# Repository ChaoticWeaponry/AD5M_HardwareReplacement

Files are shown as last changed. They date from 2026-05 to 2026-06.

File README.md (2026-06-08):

# AD5M Complete Hardware Replacement
A project for the Flashforge Adventurer 5M concerning complete electronic hardware replacement.  

**Special thanks to FaqT0tum for inspiring the ideas for these mods.**  

> [!WARNING]  
> **There are no warranties after you embark on this project. You must be adept in soldering and wiring.**
> 
> **PLEASE READ ALL READMES AND UNDERSTAND WHAT YOU'RE DOING BEFORE YOU START PURCHASING ITEMS OR MODIFYING YOUR PRINTER**  

A Dremel (or similar) will be required to modify various plastic bits in the rear housing of the printer to accomodate the extra components.

**Main Hardware changes in this guide:**  

-Stock Mainboard replaced with a Manta M8P V2.0 [From Amazon](https://a.co/d/01iEh6Rq)  
    -Mainboard Controller is a Raspberry Pi CM4 [From Amazon](https://a.co/d/0gnUiEp3)  
-Stock Toolhead board replaced with a MellowFly SB2040 Pro Max V3 [From AliExpress](https://www.aliexpress.us/item/3256806597664801.html)  
-Stock PSU replaced with a Meanwell LRS 450 [From Amazon](https://a.co/d/0aqzs9kM)  
-Stock Display replaced with a BTT Touch HDMI5 v1.2 [From Amazon](https://a.co/d/09CFqlyS)  
-Stock Hotend replaced with a X1/X1C hotend (I used Microswiss) [From Amazon](https://a.co/d/0eQoXAdD)  

**Generic parts needed:**  

-Various M3 screws/nuts (machine thread)  
-M3 thread inserts  
-Various M3 screws (coarse/plastic thread)  
-Various M2 screws (coarse/plastic thread)  
-Various JST XH, PH and MX connectors/pins (MX for the part-fan)  
-12, 16, 18, 22 and 24 gauge wiring (longest lengths will be 18 and 24 gauge for the toolhead harness)  
-A LOT of a robust filament that can handle stress and heat (I used PETG-CF)  

> [!NOTE]
> **Section or part specific parts will be listed in their respective sections.**  

**Please feel free to reach out if something doesn't make sense or specific details are missing, I tried to be thorough with the write-up, but it has taken a long time.**

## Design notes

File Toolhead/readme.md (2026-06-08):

# Toolhead Section  

**Document of Schematics/Installation/Configuration** [Fly Wiki](https://mellow.klipper.cn/en/docs/category/fly-sb2040-pro-v3)  

Specific Parts Needed  

-2X Honeywell SM453R Omnipolar Magnetic Switch (T092-3) [From DigiKey](https://www.digikey.com/short/qbd3v8pj) (I would buy extra just in case)  
-A right angle 2 pin JST-XH connector for the hotend connection.  
-A set of '2x2' Molex Microfit 3.0 connectors (buy a couple so you have extras) [From Amazon](https://a.co/d/008s7Y0V)  
-A set of 9x9x12 Stick on Heatsinks for the Motor Driver [From Amazon](https://a.co/d/09exRvM4)  
-A 30x15mm 24v fan, 2 wire.  
-A straight 2 pin JST-XH connector for the hotend thermistor (you need to change the X1 thermistor connector to JST-XH)  
-Some 1/4" PET braided sleeving to protect the wiring harness [From Amazon](https://a.co/d/0aQ7BoMF)  

> [!NOTE]
> Make sure you purchase the correct Molex Microfit 3.0 pins, a lot of listings support 20-24 gauge wiring, you must purchase 18 gauge specific pins for the power connections.

The XT30 power connector, side pin header for the secondary board, thermistor connector, hotend connector, fan header and extruder motor connectors will need to be removed/desoldered. If you have a desoldering pump, it will make your life easier when you install the replacement connectors and wiring.  

**Before:**  
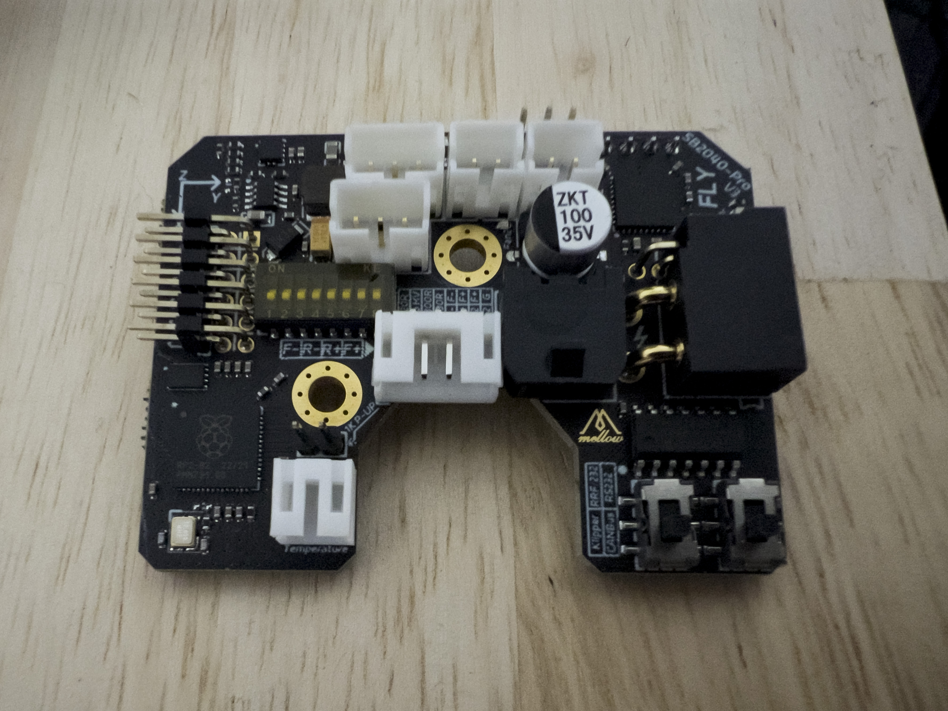
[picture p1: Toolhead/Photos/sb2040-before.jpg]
Before Removal
  
**After:**  
After Removal  

> [!NOTE]
> In my case, using a small set of flush cutters to cut the XT30 pins individually helped with desoldering. The rest of the pins didn't give me many issues.  

**SB2040 Pinout:**  
SB2040 Pinout  

**SB2040 Wiring:**  
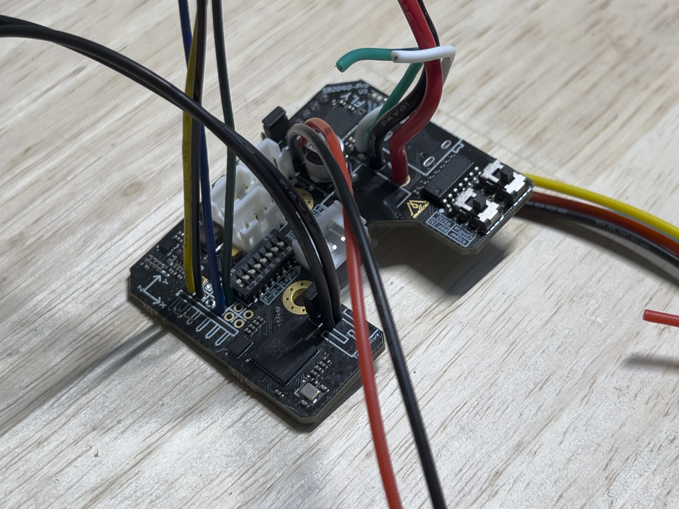
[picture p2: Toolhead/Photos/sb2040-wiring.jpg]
SB2040 Wiring
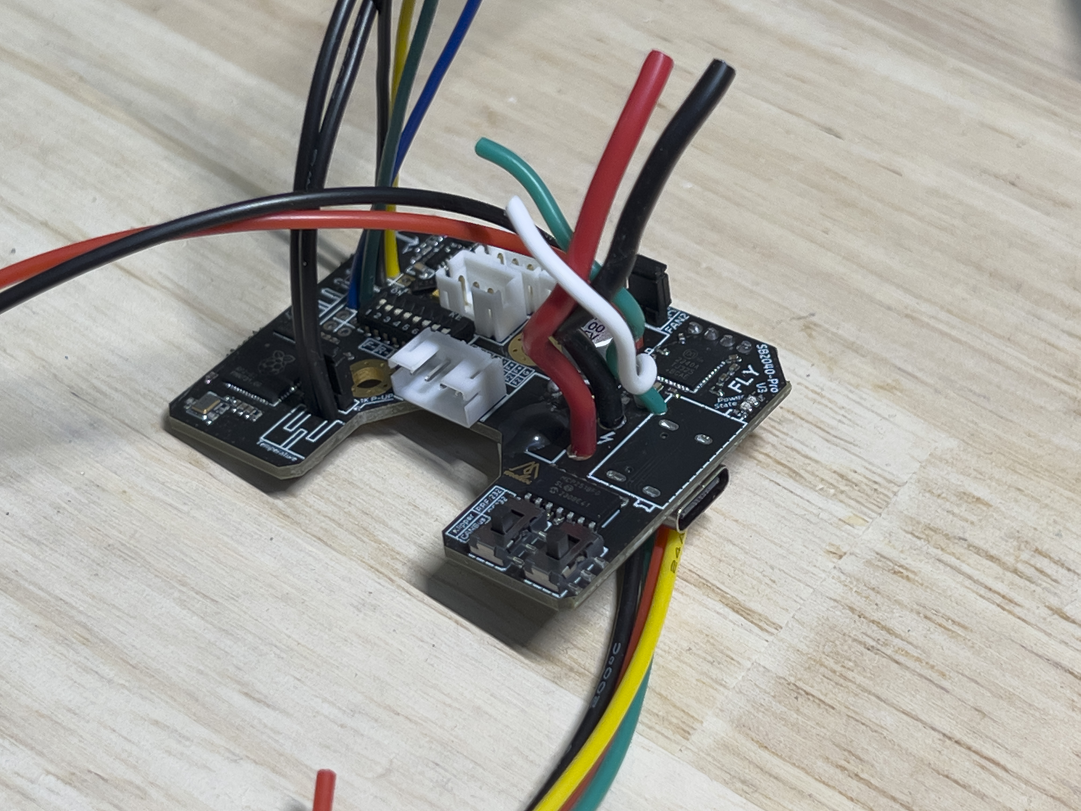
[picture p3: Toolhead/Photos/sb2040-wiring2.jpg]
SB2040 Wiring
   
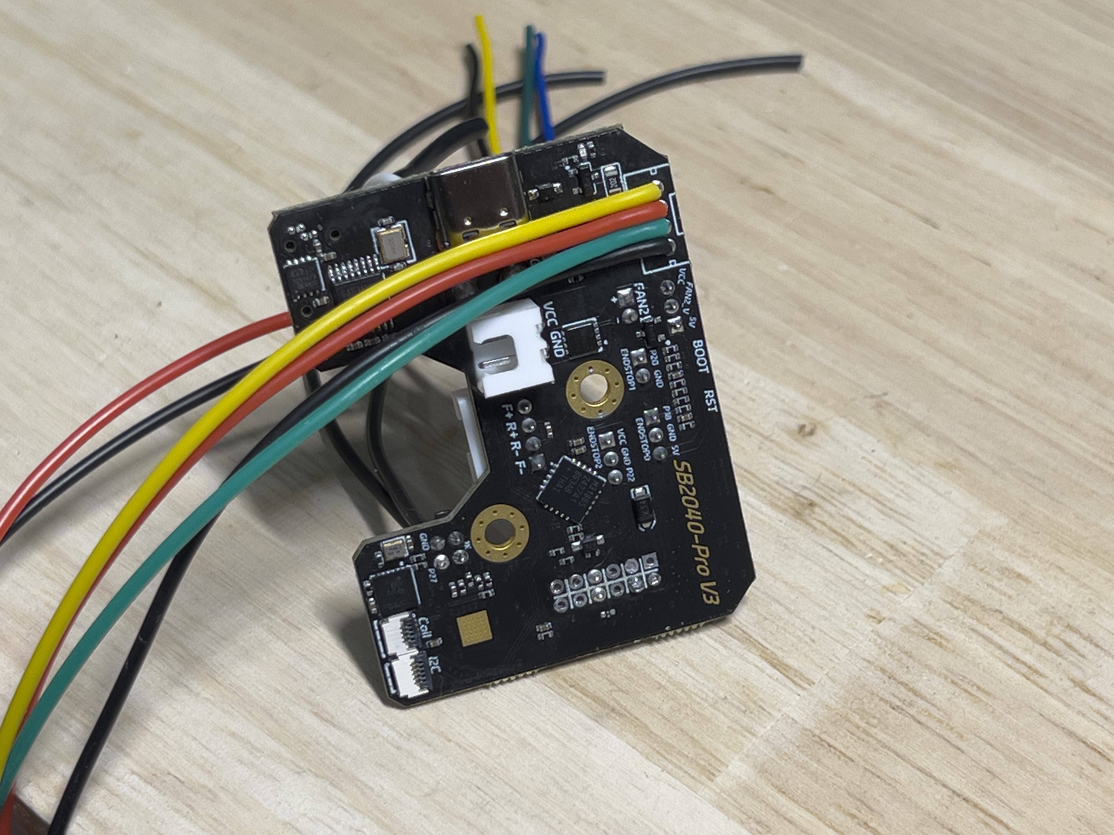
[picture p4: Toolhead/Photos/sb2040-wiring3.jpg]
SB2040 Wiring
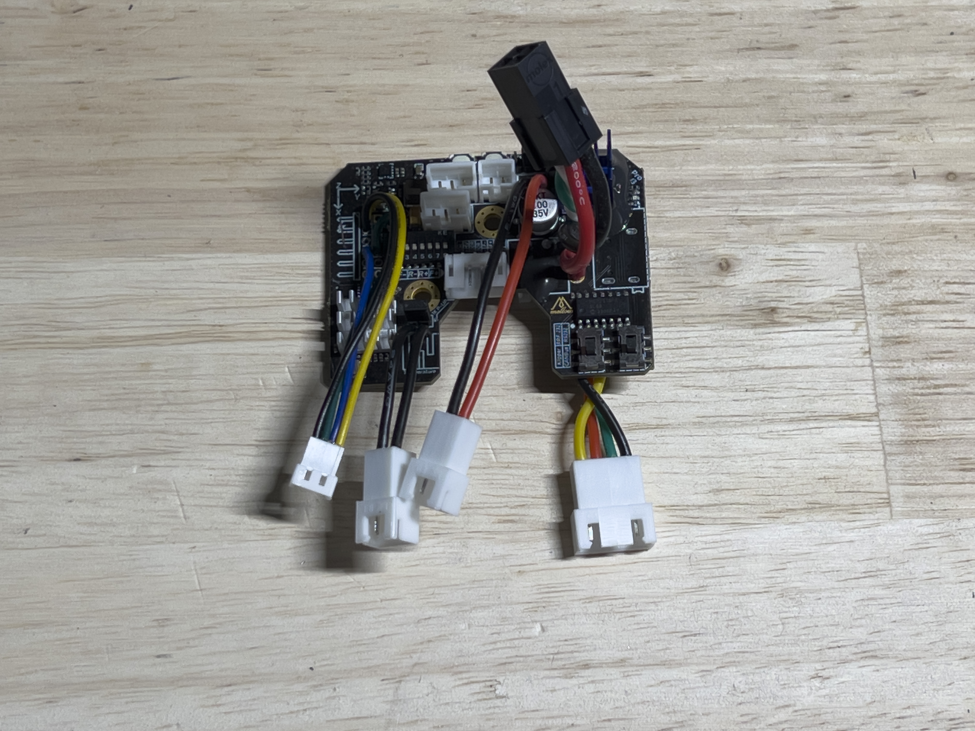
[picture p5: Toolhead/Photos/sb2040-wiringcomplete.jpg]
SB2040 Completed Wiring
   

> [!NOTE]
> I used 18 gauge wiring for the main power to the Molex Microfit 3.0 and 24 gauge wiring for the rest of the circuits.  
> I would recommend smaller wiring for the part fan connector (I disassembled some PC fan extension cables), the JST MX connectors/pins are ***TINY.***

**Toolhead Connectors:**  
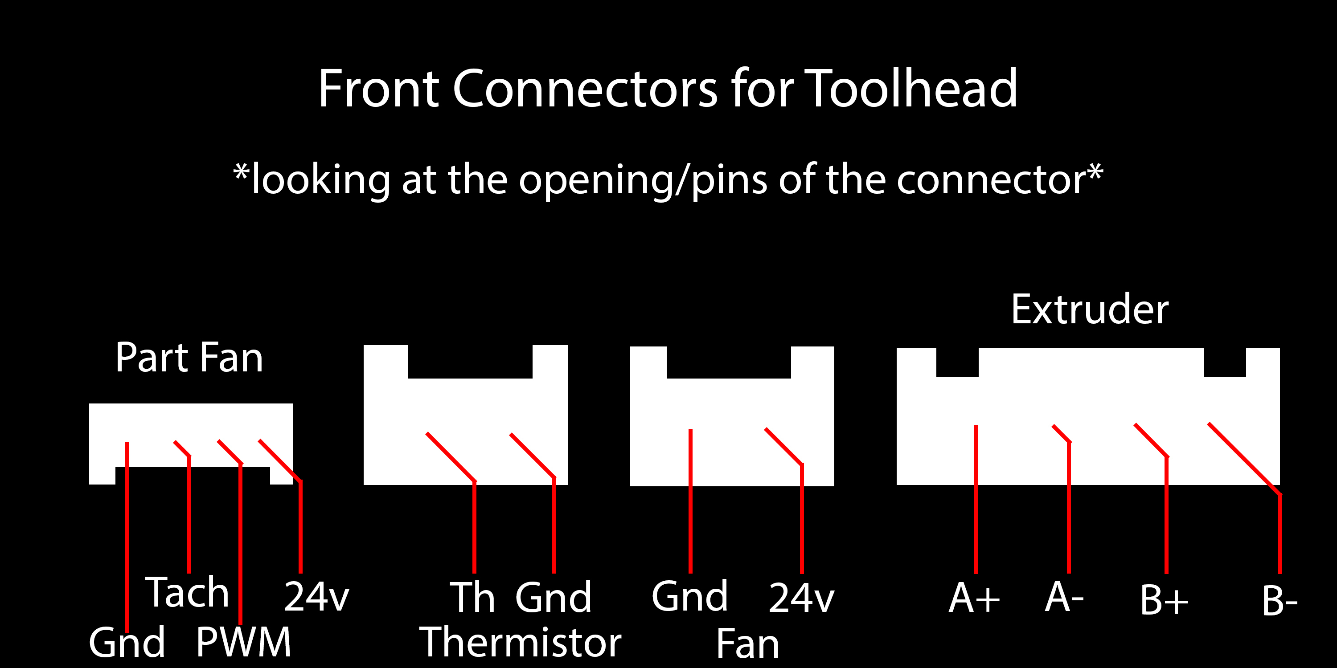
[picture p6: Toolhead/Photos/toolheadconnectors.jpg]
Toolhead Connectors
  

I would strongly recommend upgrading the SB2040's included driver heatsink, I used a 'stick-on' 9x9x12mm heatsink and potted it to assist with vibration resistance. I added a small heatsink to the Raspberry Pi controller as well.  
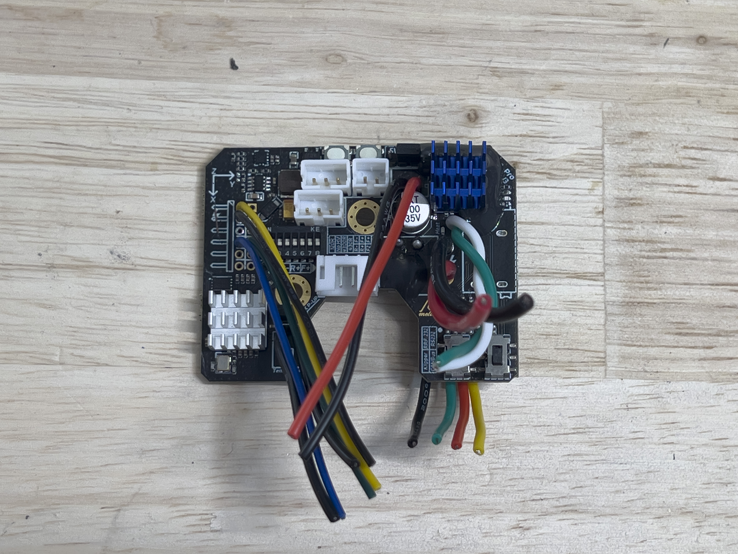
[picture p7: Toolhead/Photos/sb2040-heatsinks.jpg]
SB2040 Heatsinks
  

**Part Fan:**  
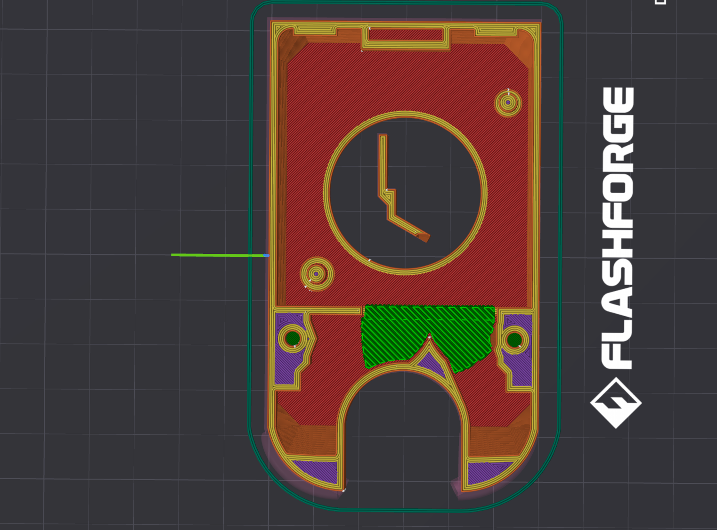
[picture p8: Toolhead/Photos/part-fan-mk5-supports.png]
Part Fan Supports
  
Make sure you use support painting on the part fan, above is a general guideline for where the supports should be.  

**Toolhead Body:**  
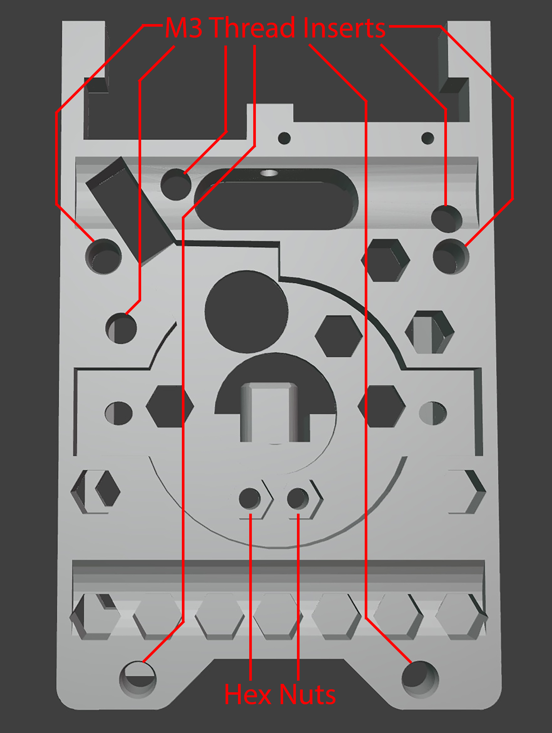
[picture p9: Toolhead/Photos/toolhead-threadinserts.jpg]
Toolhead Thread Inserts
  
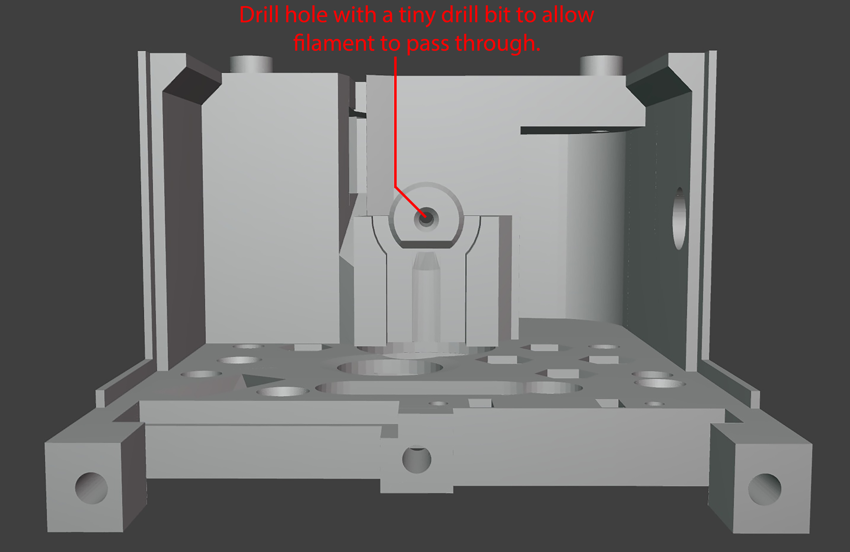
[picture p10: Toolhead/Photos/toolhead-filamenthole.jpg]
Toolhead Filament Hole
  

**Toolhead MR Sensors:**  
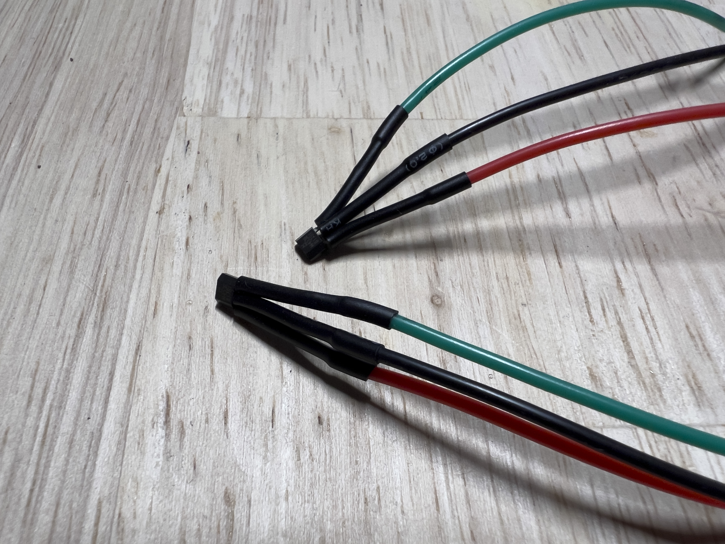
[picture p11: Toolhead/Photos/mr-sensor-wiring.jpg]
MR Sensor Wiring
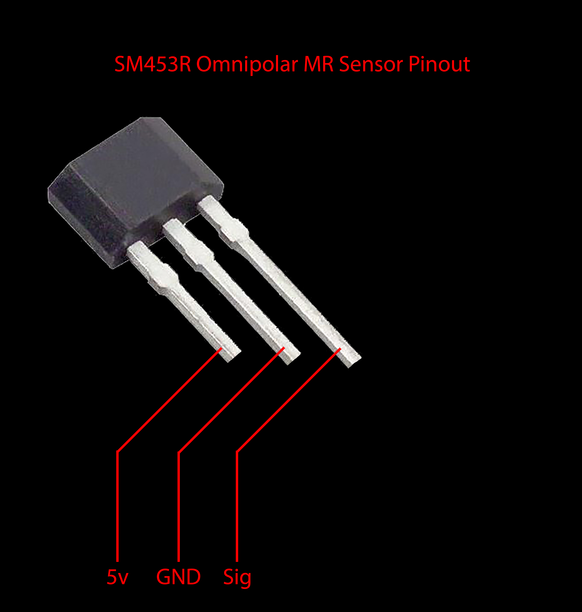
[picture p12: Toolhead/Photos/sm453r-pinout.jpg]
MR Sensor Pinout
   

> [!NOTE]
> When inserting the MR sensors into the toolhead cap, make sure they are completely bottomed out, the top of the sensor (opposite of the leads) is inserted first, the holes should be a snug fit. Only epoxy the areas surrounding the MR sensor to hold it in place. Epoxy ***should not*** contact the sensing faces.
> 
> In my case, it was easiest to trim the leads to ~1/2 the original length, solder the wires, heatshrink the connections, then bend everything to a 90 degree angle. The rounded face of the sensor should face the bottom on the Y endstop, towards the front on the X endstop.  

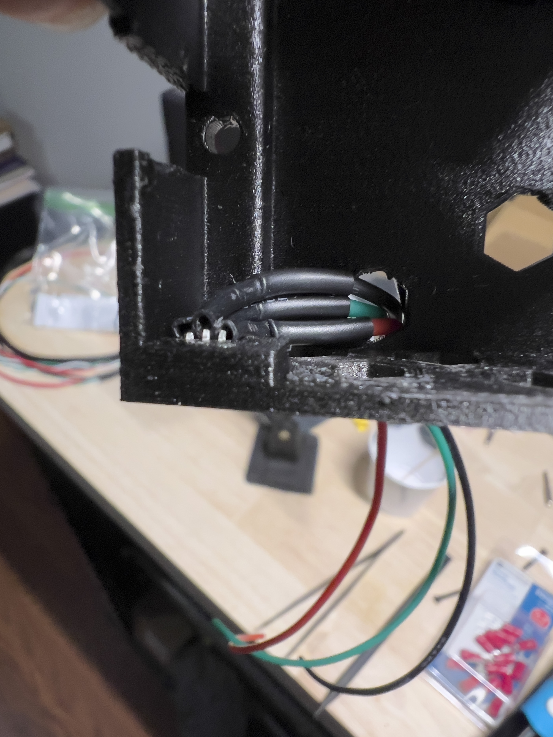
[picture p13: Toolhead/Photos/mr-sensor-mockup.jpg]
MR Sensor Mockup
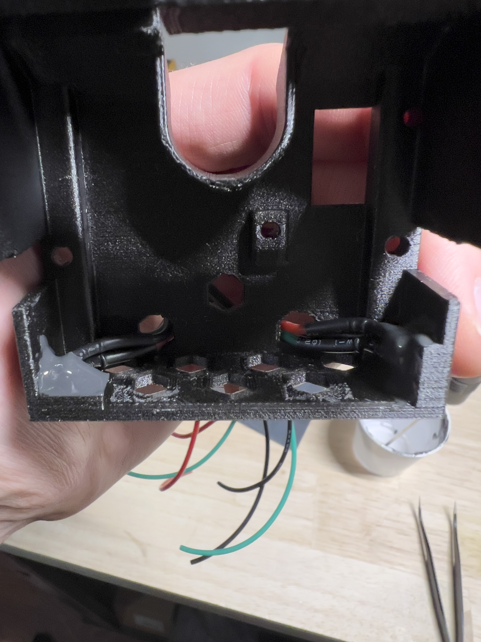
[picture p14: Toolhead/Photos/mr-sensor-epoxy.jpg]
MR Sensor Epoxy
   

The MR sensors will be ***sharing a 5v pin*** from the 3pin endstop connector. The Y endstop sensor will utilize the 3pin endstop connector, the X endstop sensor will utilize the 2pin endstop connector.  
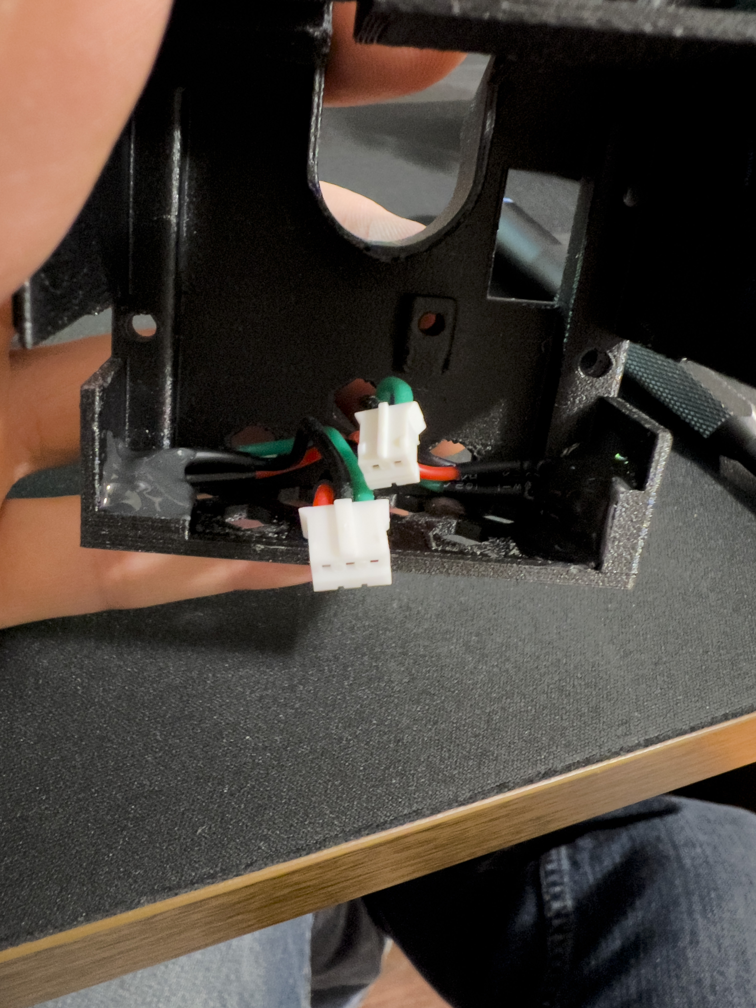
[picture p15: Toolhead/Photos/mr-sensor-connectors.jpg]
MR Sensor Connectors
  

**Original Extruder Modifications:**  
You will need to cut off the original 30x10 fan mounts from the stock extruder and remove the top tabs that hold the original fan wiring. This will make the top flush and give more room around the extruder.  

**Toolhead Cap:**  
The printed part of the toolhead cap has 2 'shields' built into it to prevent supports from building on the MR sensor areas.  

**Toolhead Harness:**  
I intentionally made my harness long so I could shorten later. My harness was a little over 1 meter long when completed.  
It will be 2x 18 gauge power wires and 2x 24 gauge CAN wires. Make sure you twist the 24 gauge wires to avoid interference.  
I used a braided PET sleeve to cover and protect the wires from chafing. Heat shrink over the end of the sleeving near the toolhead connector (where the clamp is).  

**Toolhead Assembly Order:**  

1: Toolhead body prep, insert heat-set inserts and hex nuts for the hotend. Drill out 'tube' between extruder and hotend with a tiny drill bit.  
2: Install hotend. Apply blue threadlocker to the M3 screws. I make sure the hotend is bottomed out while torquing the screws.  
3: Install 30x15 hotend fan, intake from the outside blowing air toward the hotend.  
4: Install extruder motor to the toolhead assembly, route wiring through the rectangular hole.  
5: Install extruder assembly and tighten the 3 screws.  
6: Install printed part "board mount" that is located just above the extruder. You may wish to use M2 coarse screws to clamp in place, they are recommended but not absolutely neccessary.  
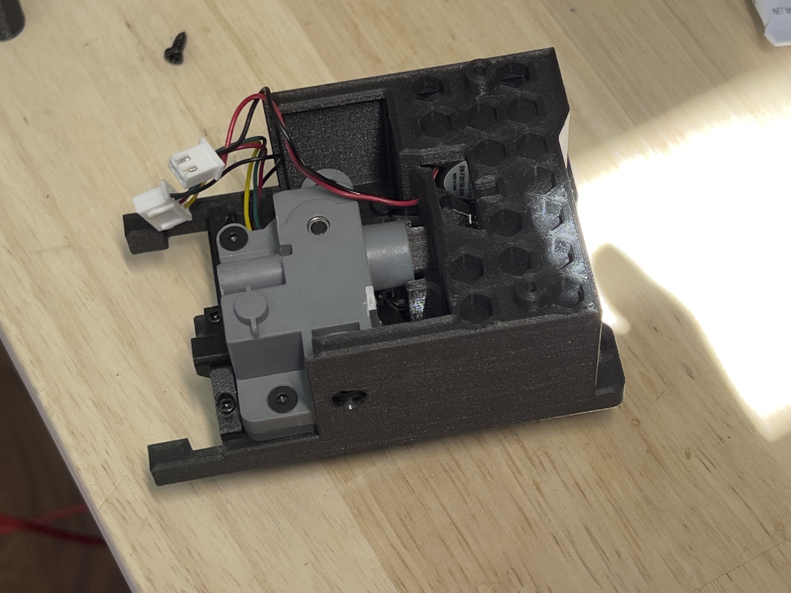
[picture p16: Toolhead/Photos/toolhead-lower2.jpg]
Toolhead Lower
  
7: Install SB2040 board using 2 coarse M3 screws. Plug in hotend heater connection.  
8: Install the toolhead cap, plug in the MR sensors, then fiddle with the connectors to get them routed correctly. The 2x2 4pin Molex Microfit main connection exits the cap on the top rectangular hole. The 4 other connectors should route to the front and 'clip' in place.  
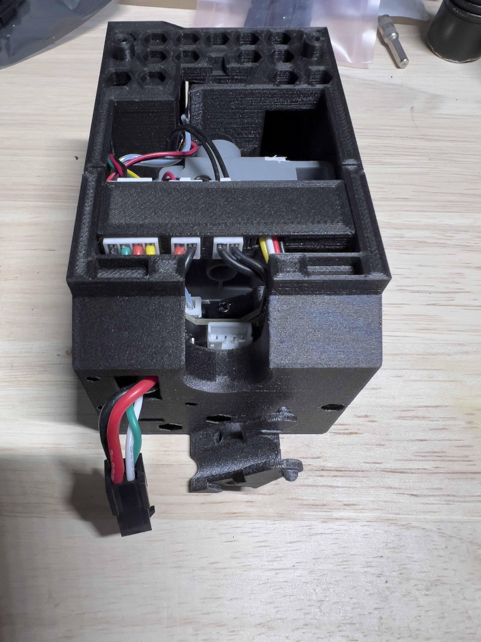
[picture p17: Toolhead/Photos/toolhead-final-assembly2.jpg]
Toolhead Final Assembly
  
9: Install front connector cover over the 4 different JST connections. Install the extruder guide (slide over the top of the extruder, it has a slot to interface correctly).  
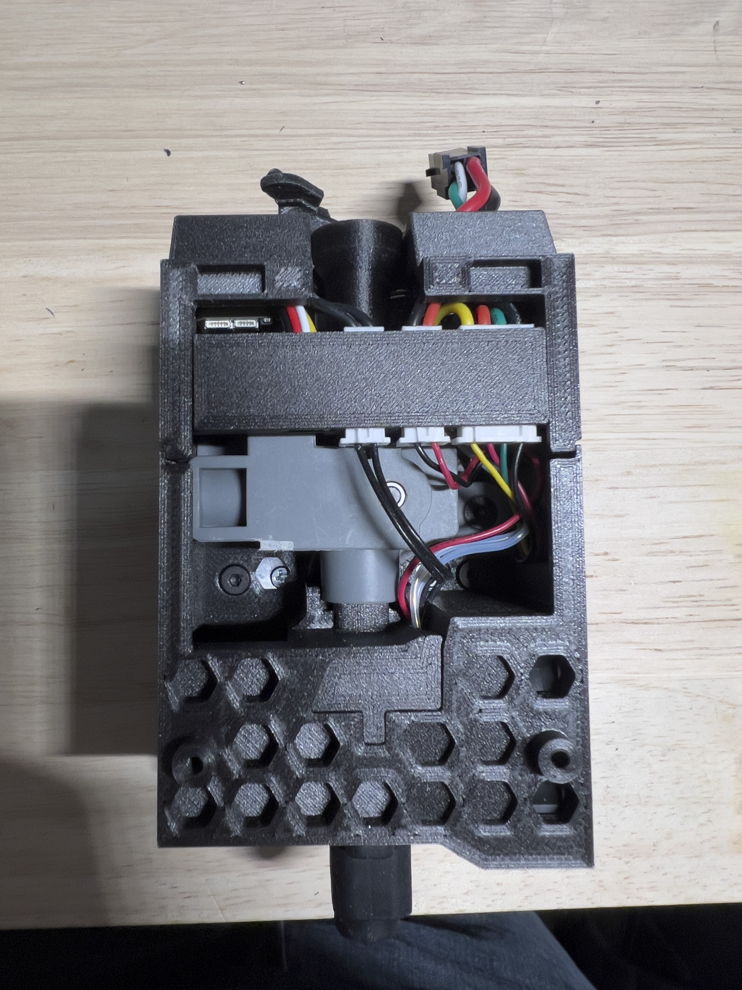
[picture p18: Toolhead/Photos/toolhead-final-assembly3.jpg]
Toolhead Final Assembly
  
10: Plug in extruder motor, hotend fan and hotend thermistor connections.  
11: Install printed part "partfan gap filler" to part fan assembly, it should be a snug fit.  
12: Install part fan to toolhead assembly, route wiring so it doesn't get pinched. Secure with M3x16 coarse screws.  
13: Install/connect main wiring harness to toolhead, attach strain relief connection and tighten screws with the wiring in the correct location.  
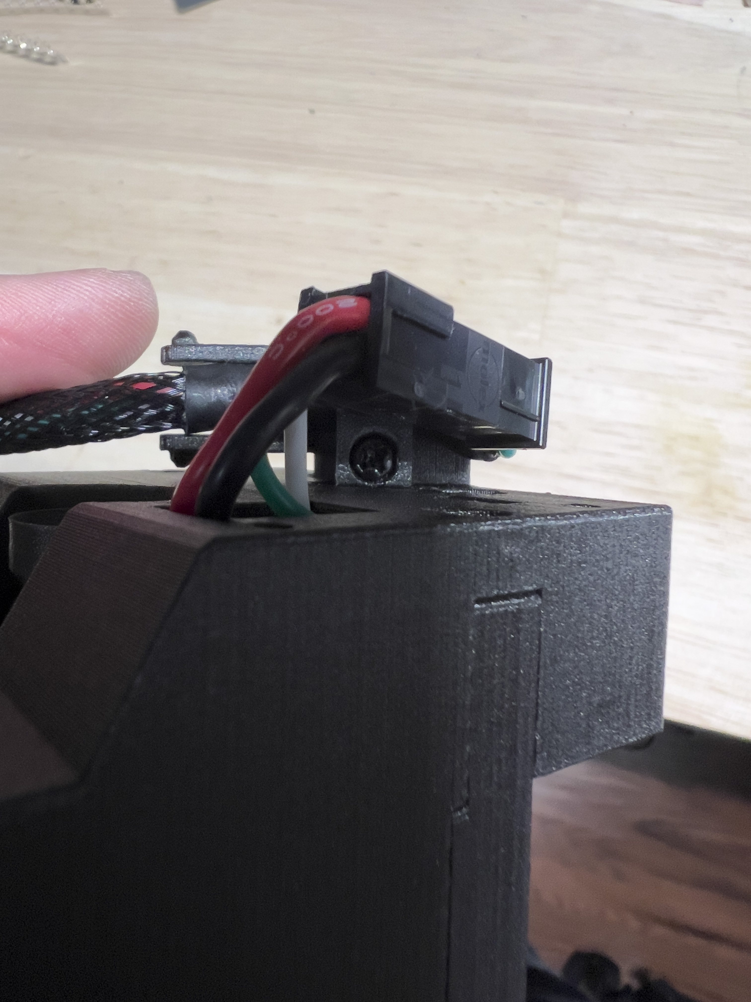
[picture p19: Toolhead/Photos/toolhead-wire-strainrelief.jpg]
Toolhead Wiring Strain Relief
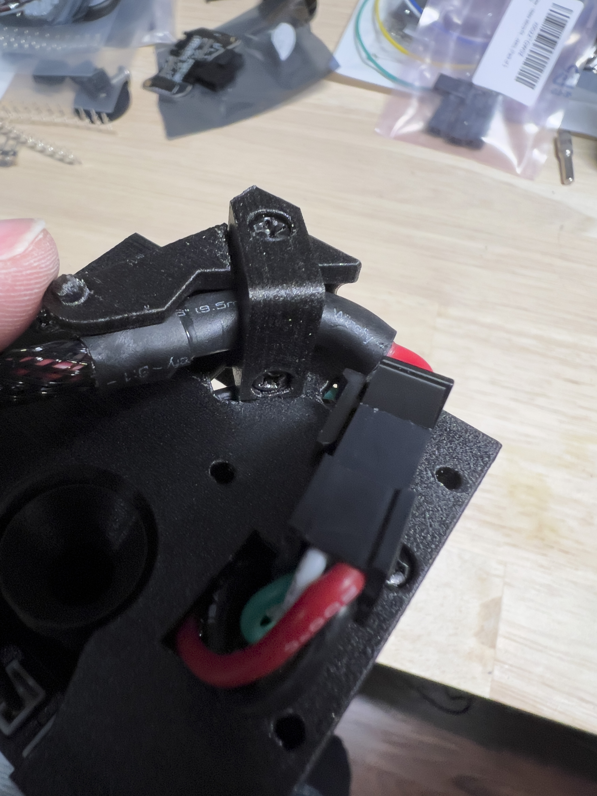
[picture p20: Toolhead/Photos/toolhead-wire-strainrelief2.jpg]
Toolhead Wiring Strain Relief
  
14: Install printed part "molex housing" with 3 M3x8 coarse screws, the Molex Microfit housing should have the release tab facing the center of the toolhead cap, it will only install one way.  
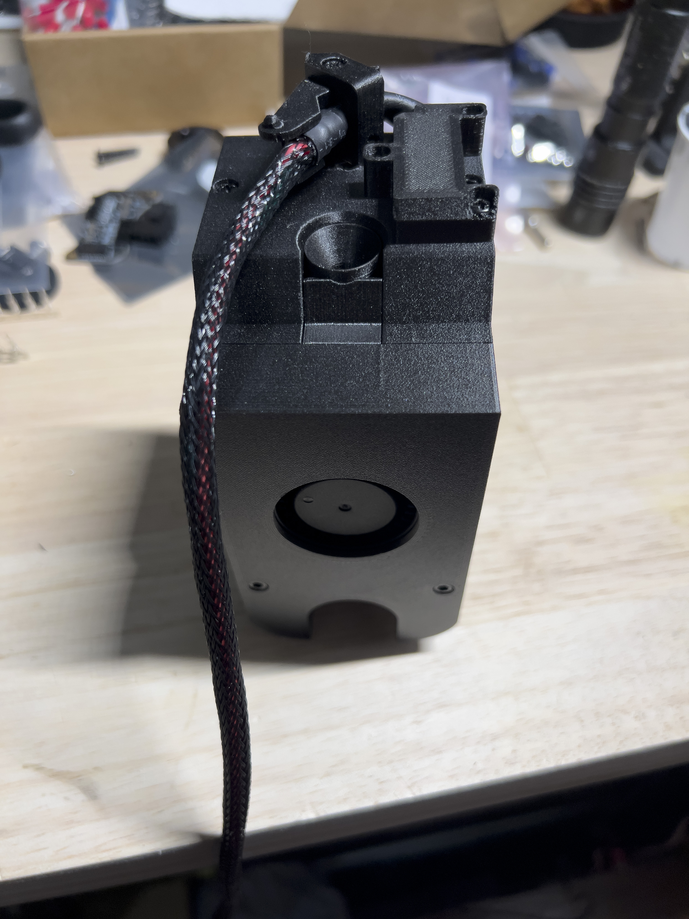
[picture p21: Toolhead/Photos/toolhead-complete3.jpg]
Toolhead Complete
  
The main assembly should be complete, route wiring harness through your drag chain assembly and back to the grommet on the printer.  

>[!NOTE]
>You may need to adjust the endstop position on the X/Y axes. This may vary depending on magnets or sensor sensitivity.  
>
>
>For X axis: Home the printer, move the head to +/- 100 and measure between the edge of the toolhead cap and the frame, compare side to side. Adjust the X endstop position until distance from toolhead to frame is the same side to side.  
>**Example:** edge of toolhead to frame at position 100 is 17mm, edge of toolhead to frame at position -100 is 13mm would mean the endstop position in the configuration would have to change by 2mm to make both measurements 15mm.  
>
>
>For Y axis: Home the printer, slowly move the toolhead until the cap is 1-2mm from contacting the front edge of the frame. Adjust the Y endstop position until you can reach -110 and have a very small gap between the toolhead cap and the front frame.

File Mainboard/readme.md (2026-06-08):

# Mainboard Section  

**Document of Schematics/Installation/Configuration** [BTT Wiki](https://global.bttwiki.com/M8P-V2_0.html)  

Parts Required:  

-FPC 30p 1mm PCB (For adapting the AD5M bed ribbon to interface with the new mainboard) [From Amazon](https://a.co/d/09iN6a9x)  
-Mainboard Dependent - 3 Stepper Motor Drivers (I used TMC2240 with my Manta M8P v2) [From Amazon](https://a.co/d/0ccSFjxs)   
-A large external MOSFET for the bed heater [From Amazon](https://a.co/d/080Fl4P3)  
-A slim 140mm fan [From Amazon](https://a.co/d/0aiYGzja)  

**MOSFET Section:**  
The Manta M8P and many other mainboard come with on-board MOSFETS to drive a bed heater. The M8P is rated to ~10 Amps, which is pretty much exactly the power rating of the stock AD5M bed heater (250w).  

I would *strongly* suggest that you include an external MOSFET like I listed above. It's stupid-overkill regarding power rating, but I would much rather err on the side of caution.  

Follow the pinouts of the respective external MOSFET that you purchase, they should be pretty self-explanatory. 2 terminals for main power in, 2 terminals for bed power out, 2 terminals for bed control (coming from the mainboard).  

**Bed Electrical Connection:**  
Bed Electrical Connections  

Above includes the pinouts for the FPC ribbon cable for the bed, as well as the pinouts for the Z-endstop and filament runout sensors.  

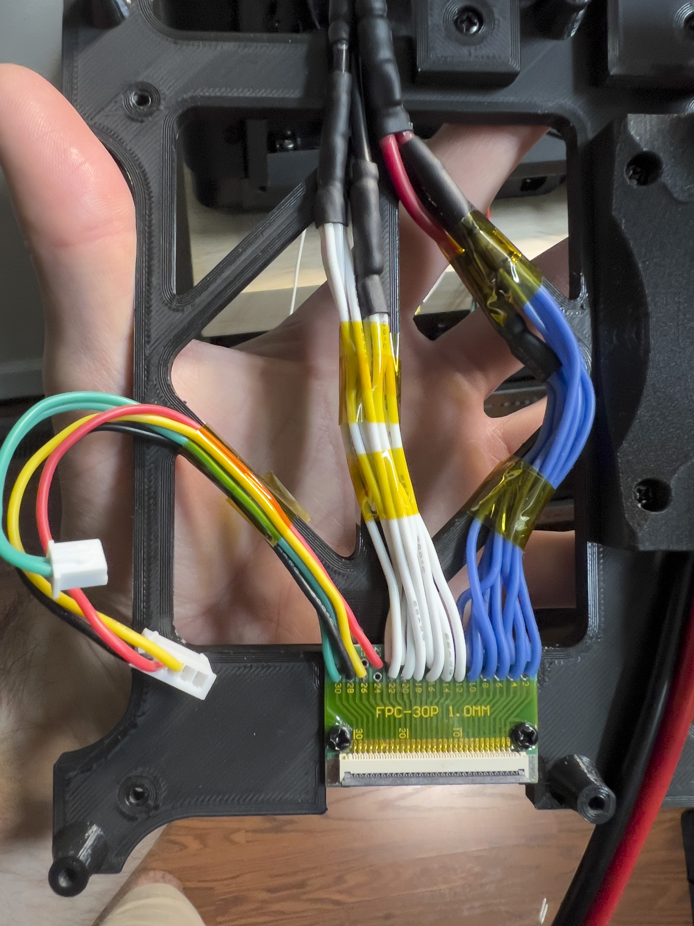
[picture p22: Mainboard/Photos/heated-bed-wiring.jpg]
Heated Bed Wiring
  

Above shows the wiring that I created to adapt to the FPC ribbon. Each one of the heater wires starts as a 22 gauge wire, these are then divided into groups of 5 and 6 and crimped into 2 separate 16 gauge wires. The two 16 gauge wires are crimped into a single 12 gauge wire.  

So for *EACH* pole of the heater, there will be 11x 22 gauge wires spliced into 2x 16 gauge wires spliced into 1x 12 gauge wire.  

**M8P Diagram:**  
M8P Diagram  

>[!NOTE]
>I did not use the filament sensor during my conversion of the printer. You should be able to wire it to any of the endstop connections and configure in your printer configuration.  
>You may elect to add additional thermistors since there are extra slots with the Manta M8P, I used thermistors on all of my stepper motors and added a chamber temperature themistor as well.

The chamber fans that I used (40mm Noctua) and all of the other fans are 12v, so you will need to select the voltages for the fans using their respective jumpers. Follow the manual for the mainboard.  

For the chamber fans, I used 2 pin JST-XH to 4 pin fan adapters, so you will lose PWM control and tachometer. Voltage control will still work to control fan speeds.  

You can re-use the stock X, Y and Z stepper motor wiring, the pinouts do not change.  

**Assembly Order:**  
1: Attech MOSFET bracket to mainboard bracket (2x M3 coarse screws)  
2: Attach FPC ribbon PCB to mainboard bracket (2x M3 coarse screws)  
3: Secure mainboard bracket assembly to the printer back housing (4x M3 coarse screws)  
4: Connect bed ribbon to FPC connector  
5: Secure M8P mainboard to mainboard bracket (4x M3 coarse screws)  
6: Connect all wiring (tweezers will come in handy grabbing the wires on the left edge of the mainboard, space is limited)  
7: Attach 140mm fan bracket to mainboard bracket (2x M3 coarse screws)  
8: Attach the 140mm fan to the fan bracket (2x long M3 coarse screws)  
9: Connect HDMI and USB for the front display  
10: If you are using the included Waveshare WiFi antenna, I have a 3D printed adapter (misc section) that plugs into the ethernet port  

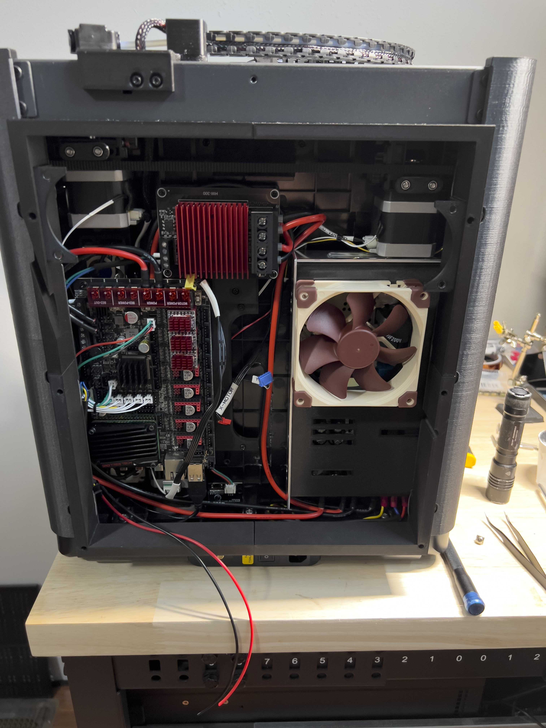
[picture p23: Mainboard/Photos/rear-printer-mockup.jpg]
Rear Printer Mockup
  

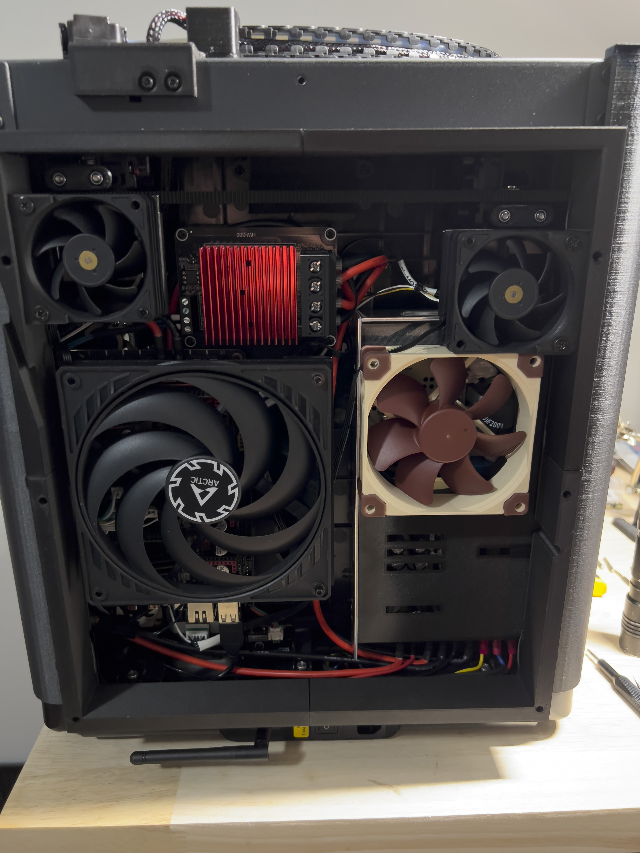
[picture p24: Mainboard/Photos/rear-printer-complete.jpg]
Rear Printer Complete
  

Rear Printer Complete With Top

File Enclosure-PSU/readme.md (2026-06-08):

# Enclosure / PSU Section  

**Parts Needed:**  
-8x 12x3mm magnets for the enclosure top.  
-6x 36mm M4 screws screws for the back housing/cover assembly.  
-3ft/1m HDMI to Micro HDMI & USB-A to USB-C cables for the display.  
-2x 40mm 12v fans for enclosure ventilation.  
-2x 60mm 12v fans for X/Y stepper motor cooling.  

I have included an STL for the replacement front cover for the Meanwell LRS-450 adding support for a 92mm fan. The stock fan runs at 12v.  
**I will not be including instructions or pictures for modification of the PSU for liability reasons. Please be careful.**  

For the overall enclosure for the printer, just use the original Flashforge enclosure kit minus the top. The parts included in the guide are for the top cover and the rear cover (with extensions). The rear covers and extensions will add roughly 40mm of depth to your printer.  

**Front Screen:**  
The back cover of the BTT Touch 5 is mounted to the top of the enclosure ***first***.  
The screen itself is pressure fit into the front cover, then you slide the front cover over the rear cover and secure with 2 M2 coarse-threaded screws.  

**Back Housing Mods:**  
Back Housing Mods for PSU  
Back Housing Mods for Mainboard  

The LRS-450 shares the same mount as the LRS-350 (and the original power supply), so no modifications are needed on the mount holes themselves.  
The entire shroud for the top enclosure fan will need to be cut flush (or close to flush) for the new board to fit.  
A lot of this will be trial and error, test fit, remove more material, test fit again, etc.  

**Top Housing:**  
I have no in-progress shots while making this, but it should be pretty self-explanatory. Print the parts, place on a large, level surface, glue together with your choice of adhesive. I generally glue the magnets into the slots after the top is glued into one piece.  
There are 2 spots for M3 thread inserts for the screen mount, make sure these are slightly recessed so the screen housing can mount flush to the top assembly. The USB and HDMI cables should slot nicely into the groove in the right side of the top assembly.  

Startup Test  

**Rear Extensions and Cover:**  
The rear extension pieces are pressure fit into each other, I placed double sided tape on the inside edge, then used the M4 screws to align the extension pieces. This will allow you to install/remove the rear cover without struggling to line multiple things up.  
The top-left extension piece has a groove cut into it to allow the USB and HDMI cables from the screen to pass through.  

The rear covers are held together with 8 total M3x10 coarse thread screws. They have tabs in the corners to help line the assemblies up.  
Back Cover Installed

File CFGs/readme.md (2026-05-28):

# Configuration Section  

The files contained in this section are a slightly modified version of the configurations of my printer. I have some optional accessories (buzzer, extra temperature sensors, different stepper motors, etc).  

**PLEASE GO THROUGH THE CONFIGURATION FILES TO MAKE SURE THEY WILL BE COMPATIBLE WITH YOUR SPECIFIC HARDWARE CONFIGURATION**  

> [!WARNING]
> Your CAN UUID's will be different than mine, follow the respective instructions for your toolhead board and mainboard to find yours.

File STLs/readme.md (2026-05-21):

# STL Section

Included in this section are all of the STL's required for the conversion.

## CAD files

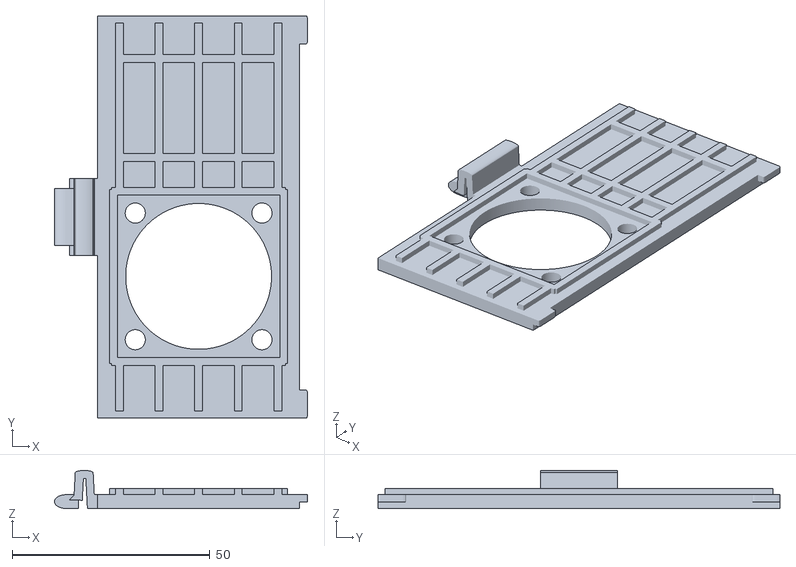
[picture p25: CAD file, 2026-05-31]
STLs/Enclosure-PSU/fanfilter-40mm-upper.stl
63.9 x 101.5 x 9.60

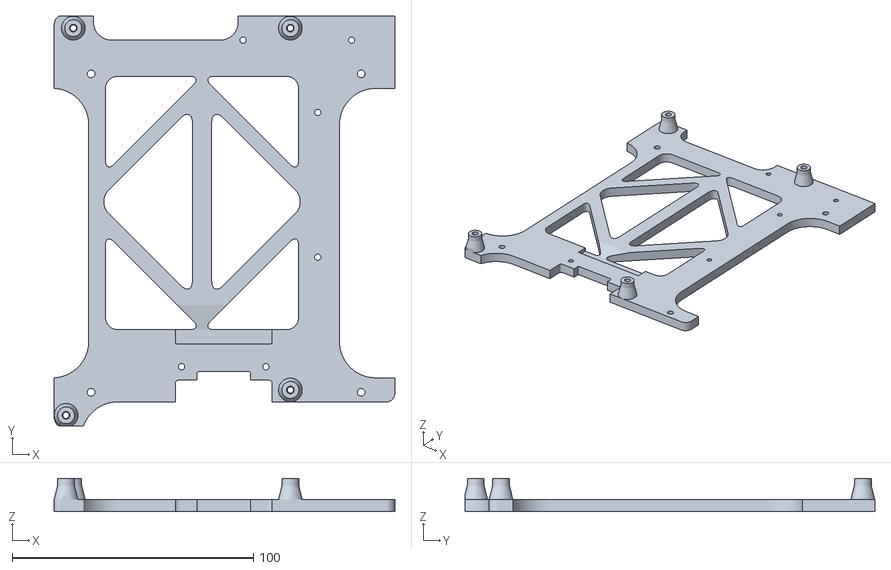
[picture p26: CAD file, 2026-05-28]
STLs/Mainboard/mantam8p-ffad5m-adapter-mk2-base.stl
141.4 x 170.0 x 13.7

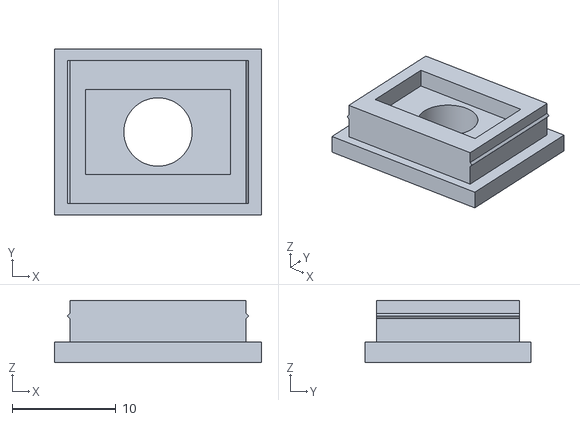
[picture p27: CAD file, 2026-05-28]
STLs/Misc/ad5m-wifi-antenna-adapter-mk1.stl
20.0 x 16.0 x 6.00

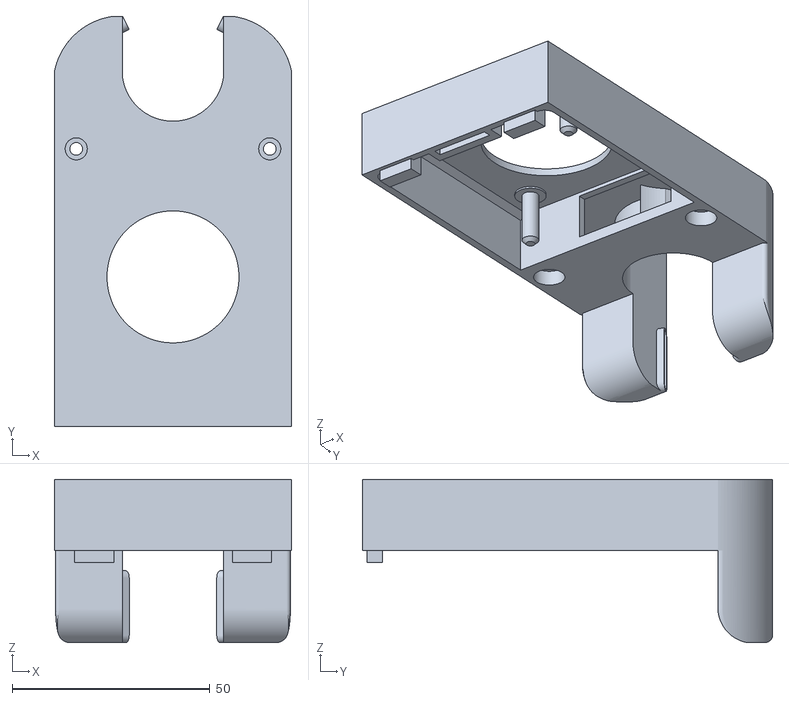
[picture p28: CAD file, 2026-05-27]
STLs/Toolhead/extruder-x1-sb2040-mk5-partfan-clearanced.stl
60.0 x 103.8 x 41.3

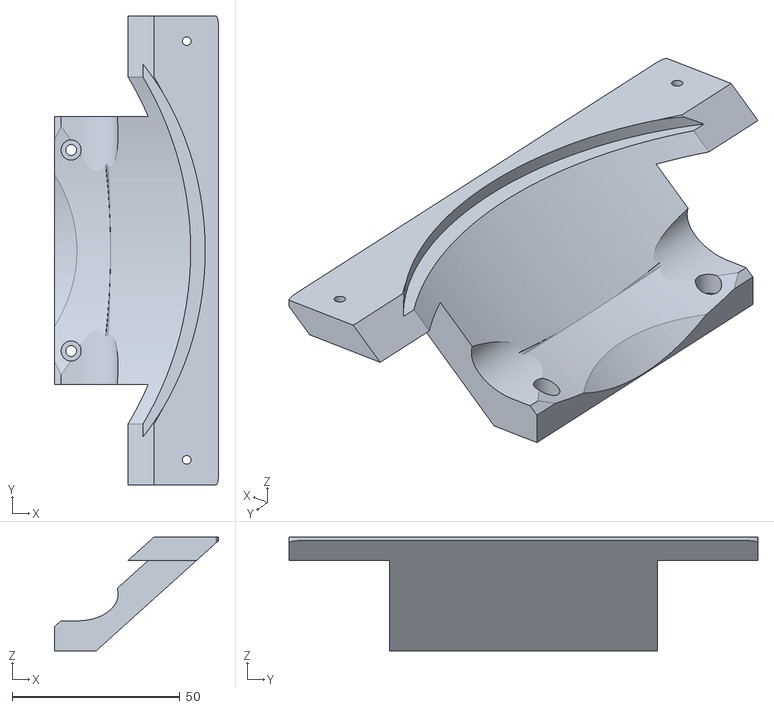
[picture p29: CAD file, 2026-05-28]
STLs/Mainboard/mantam8p-ffad5m-adapter-140fan-mk5.stl
49.0 x 140.0 x 34.0

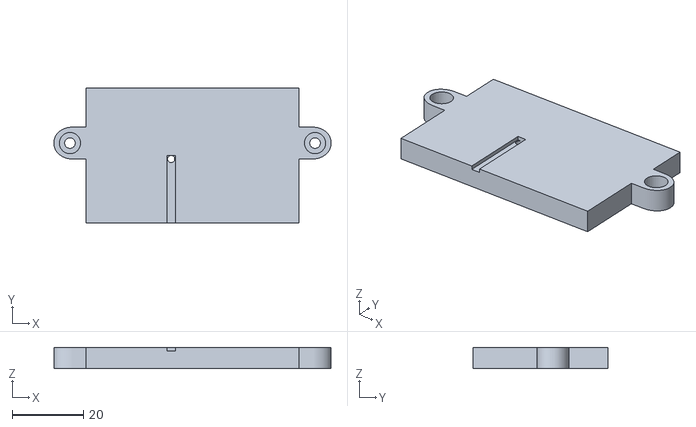
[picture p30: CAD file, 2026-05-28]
STLs/Misc/mantam8p-ffad5m-adapter-mk2-chamber-thermistorplate.stl
78.0 x 38.0 x 6.00

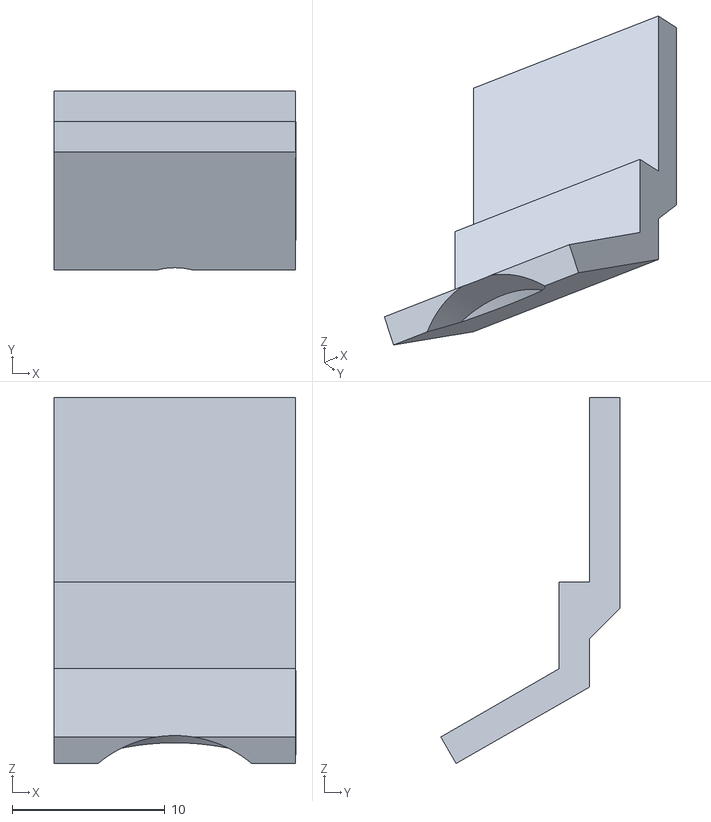
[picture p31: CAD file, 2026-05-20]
STLs/Toolhead/extruder-x1-sb2040-mk5-partfan-gapfiller.stl
15.8 x 11.7 x 23.9

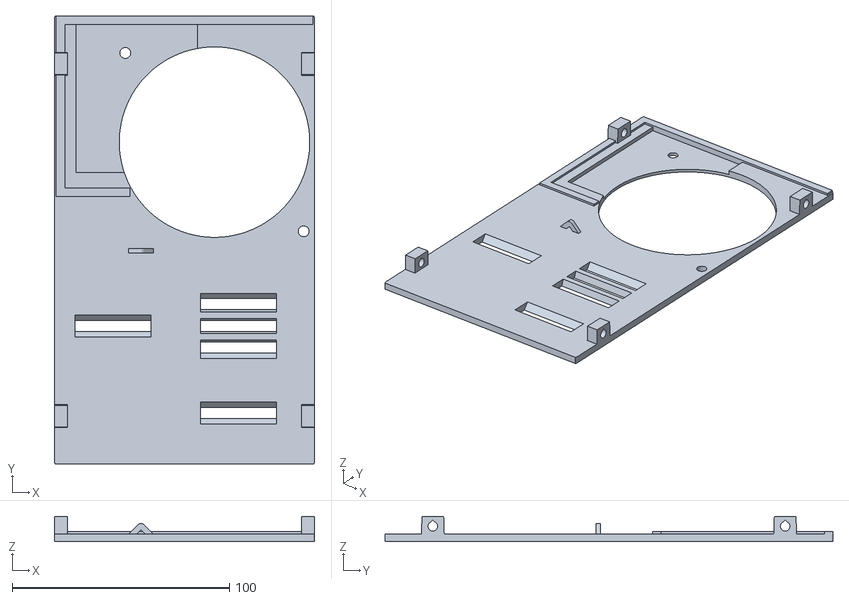
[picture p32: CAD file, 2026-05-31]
STLs/Enclosure-PSU/mw-lrs450-frontpanel-mk2.stl
119.6 x 206.0 x 11.5

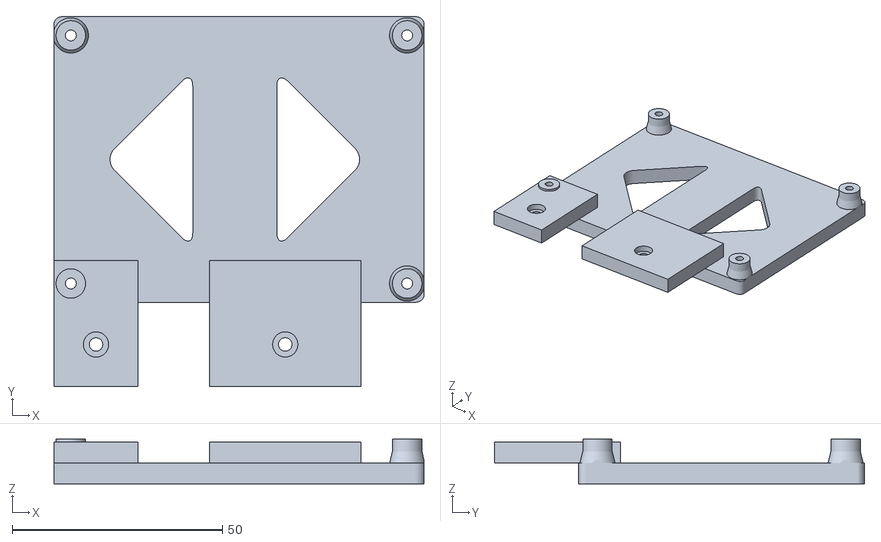
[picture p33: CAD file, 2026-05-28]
STLs/Mainboard/mantam8p-ffad5m-adapter-mk2-mosfet.stl
88.0 x 88.0 x 10.7

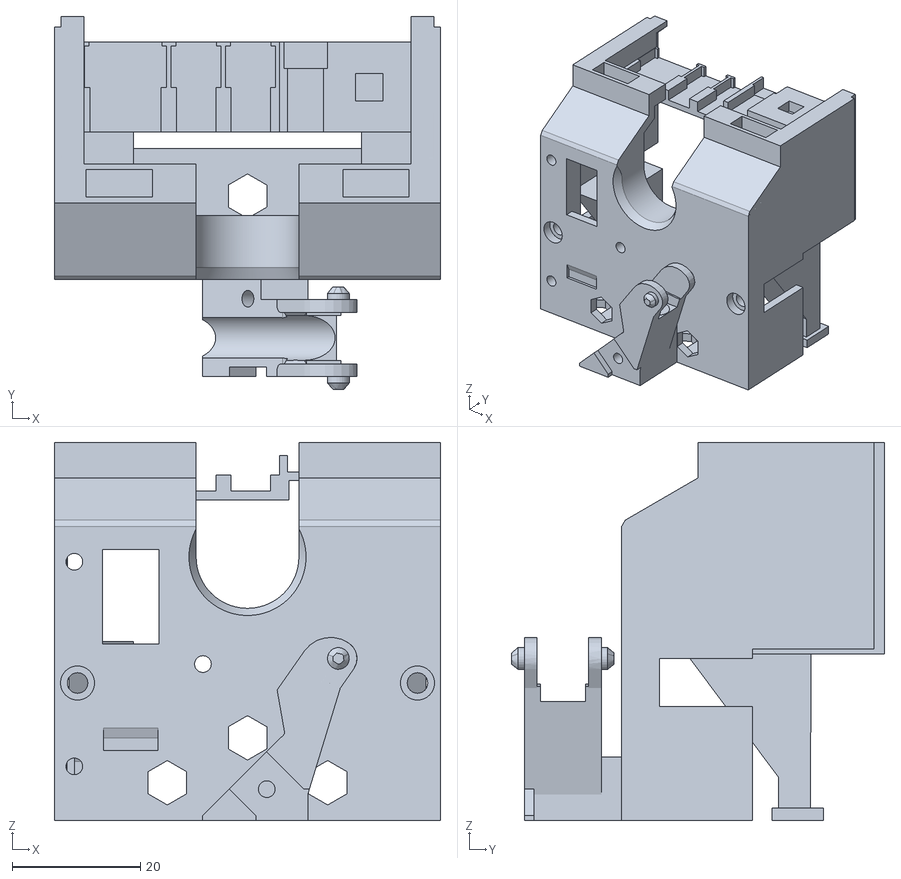
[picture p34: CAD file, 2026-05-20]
STLs/Toolhead/extruder-x1-sb2040-mk5-cap.stl
60.2 x 58.1 x 59.0

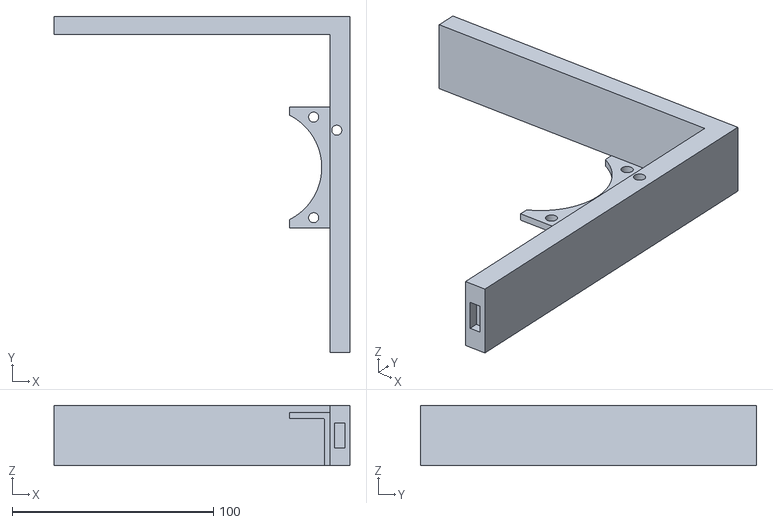
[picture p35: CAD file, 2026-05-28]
STLs/Enclosure-PSU/ad5m-backpanel-spacer-top-right.stl
147.0 x 167.0 x 30.0

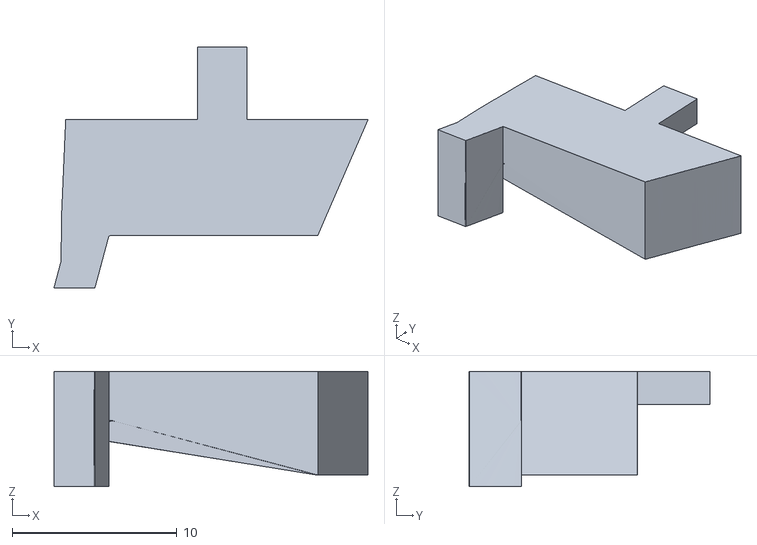
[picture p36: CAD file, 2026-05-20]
STLs/Toolhead/extruder-x1-sb2040-mk5-body-nozzlecover.stl
19.1 x 14.6 x 7.00

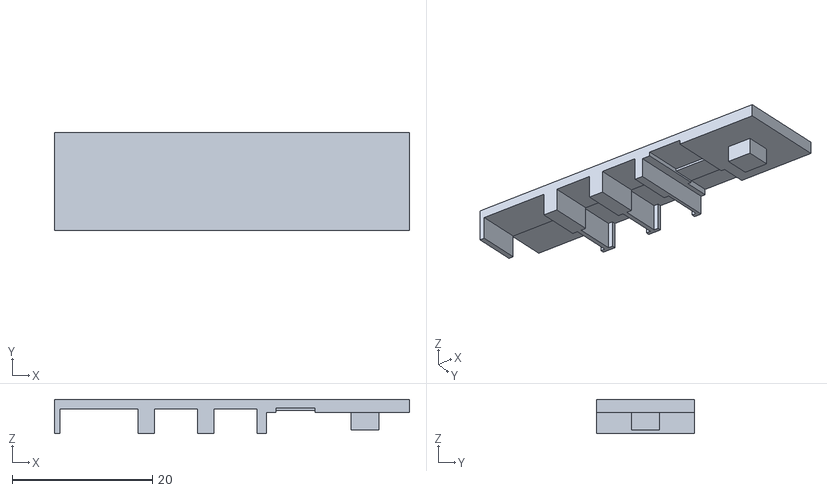
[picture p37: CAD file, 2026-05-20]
STLs/Toolhead/extruder-x1-sb2040-mk5-cap-frontconnectorcover.stl
50.7 x 14.0 x 4.90

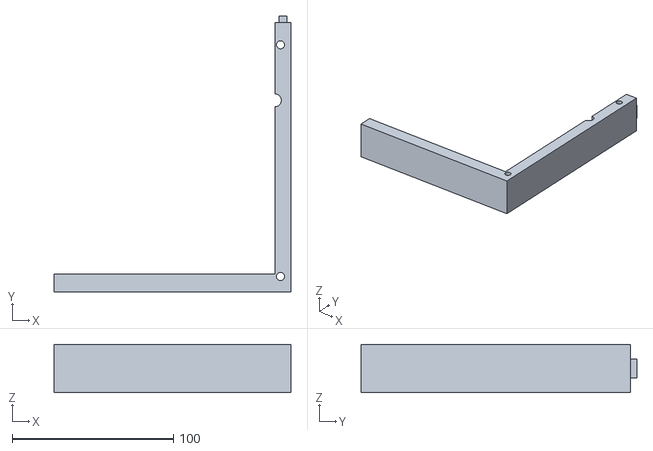
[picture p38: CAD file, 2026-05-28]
STLs/Enclosure-PSU/ad5m-backpanel-spacer-bottom-right.stl
147.0 x 171.0 x 30.0

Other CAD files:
STLs/Enclosure-PSU/fanfilter-40mm-lower.stl
STLs/Enclosure-PSU/ad5m-backpanel-spacer-top-left.stl
STLs/Toolhead/extruder-x1-sb2040-mk5-cap-molexhousing.stl
STLs/Enclosure-PSU/ad5m-backpanel-spacer-bottom-left.stl
STLs/Enclosure-PSU/5in-screen-frontbezel.stl
STLs/Enclosure-PSU/5in-screen-rearbezel.stl
STLs/Enclosure-PSU/ad5m-backpanel-spacer-cover-botleft.stl
STLs/Enclosure-PSU/ad5m-backpanel-spacer-cover-botright.stl
STLs/Enclosure-PSU/ad5m-backpanel-spacer-cover-topleft.stl
STLs/Enclosure-PSU/ad5m-backpanel-spacer-cover-topright.stl
STLs/Enclosure-PSU/ad5m-clearanced-mini-top-frontleft.stl
STLs/Enclosure-PSU/ad5m-clearanced-mini-top-frontright.stl
STLs/Enclosure-PSU/ad5m-clearanced-mini-top-rearleft.stl
STLs/Enclosure-PSU/ad5m-clearanced-mini-top-rearright.stl
STLs/Enclosure-PSU/ad5m-drag-chain-mount-dragchain-base.stl
STLs/Enclosure-PSU/ad5m-drag-chain-mount-dragchain-top.stl
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

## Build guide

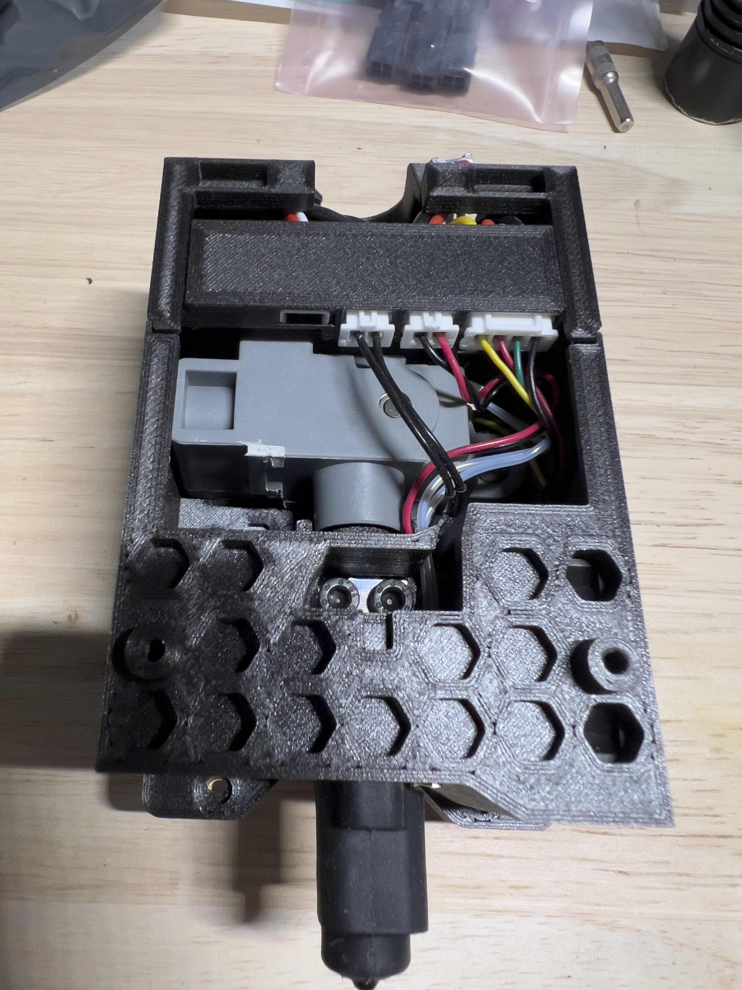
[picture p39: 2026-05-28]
Toolhead/Photos/toolhead-final-assembly.jpg

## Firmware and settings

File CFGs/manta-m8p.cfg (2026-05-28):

# This file contains common pin mappings for the BIGTREETECH Manta M8P V2.0
# To use this config, the firmware should be compiled for the
# STM32H723 with a "128KiB bootloader" "25 MHz crystal"
# and "USB (on PA11/PA12)", "CAN bus (on PD0/PD1)" or Serial (on USART1 PA10/PA9).

# See docs/Config_Reference.md for a description of parameters.

[temperature_sensor MantaM8P]
sensor_type: temperature_mcu

# Motor1
[stepper_x]
step_pin: PE6
dir_pin: PE5
enable_pin: !PC14
microsteps: 32
#full_steps_per_rotation: 400
rotation_distance: 40
endstop_pin: !SB2040:gpio20
position_endstop: 105
position_max: 110
position_min: -110
homing_speed: 40
homing_retract_dist: 7.5
homing_retract_speed: 20
second_homing_speed: 5

# Motor2
[stepper_y]
step_pin: PE2
dir_pin: PE1
enable_pin: !PE4
microsteps: 32
#full_steps_per_rotation: 400
rotation_distance: 40
endstop_pin: !SB2040:gpio18
position_endstop: 100
position_max: 110
position_min: -110
homing_speed: 40
homing_retract_dist: 7.5
homing_retract_speed: 20
second_homing_speed: 5

# Motor3
[stepper_z]
step_pin: PB8
dir_pin: PB7
enable_pin: !PE0
microsteps: 32
#full_steps_per_rotation: 400
rotation_distance: 8
endstop_pin: ^PF4
position_endstop: 222
position_max: 230
position_min: -10
homing_speed:20
homing_retract_dist: 5
homing_retract_speed: 12.5
second_homing_speed: 5

## Motor4
# The M8P only has 4 heater outputs which leaves an extra stepper
# This can be used for a second Z stepper, dual_carriage, extruder co-stepper,
# or other accesory such as an MMU
#[stepper_]
#step_pin: PB4
#dir_pin: PB3
#enable_pin: !PB6
#endstop_pin: ^PF1
#...

# Motor5
#[extruder]
#step_pin: PG13
#dir_pin: PG12
#enable_pin: !PG15
#microsteps: 16
#rotation_distance: 33.500
#nozzle_diameter: 0.4
#filament_diameter: 1.75
#heater_pin: PA0 # HE0
#sensor_pin: PB0 # T0
#sensor_type: Generic 3950
#control: pid
#pid_Kp: 22.2
#pid_Ki: 1.08
#pid_Kd: 114
#min_temp: -100
#max_temp: 250

## End-Stop 5
#[filament_switch_sensor material_0]
#switch_pin: PF0

## Motor6
#[extruder1]
#step_pin: PG9
#dir_pin: PD7
#enable_pin: !PG11 
#heater_pin: PA1 # HE1 
#sensor_pin: PC5 # T1
#...

## End-Stop 6
#[filament_switch_sensor material_1]
#switch_pin: PC15

## Motor7
#[extruder2]
#step_pin: PD4
#dir_pin: PD3
#enable_pin: !PD6
#heater_pin: PA3 # HE2
#sensor_pin: PC4 # T2
#...

## Motor8
#[extruder3]
#step_pin: PC7
#dir_pin: PC8
#enable_pin: !PD2
#heater_pin: PA5 # HE3
#sensor_pin: PA7 # T3
#...

[heater_bed]
heater_pin: PA0
sensor_pin: PB1 # TB 
sensor_type: ATC Semitec 104GT-2
min_temp: -100
max_temp: 130

#[temperature_sensor X-Motor]
#sensor_pin: PB0
#sensor_type: Generic 3950
#min_temp: -100
#max_temp: 100

#[temperature_sensor Y-Motor]
#sensor_pin: PC5
#sensor_type: Generic 3950
#min_temp: -100
#max_temp: 100

#[temperature_sensor Z-Motor]
#sensor_pin: PC4
#sensor_type: Generic 3950
#min_temp: -100
#max_temp: 100

#[temperature_sensor Chamber]
#sensor_pin: PA7
#sensor_type: Generic 3950
#min_temp: -100
#max_temp: 100

#[fan_generic soc-fan]
#pin: host:gpio79  #CB1
#pin: host:gpio26  #CM4

# Fan0
[fan_generic Chamber_Exhaust]
pin: PF7
cycle_time: 0.00005
kick_start_time: 0.3

# Fan1
[fan_generic Chamber_Intake]
pin: PF9
cycle_time: 0.00005
kick_start_time: 0.3

## Fan2
#[heater_fan fan2]
#pin: PF6

## Fan3
#[heater_fan fan3]
#pin: PF8

## Fan4
#[heater_fan fan4]
#pin: PA4

## Fan5
[fan_generic Mainboard]
pin: PA6
tachometer_pin: PC2
hardware_pwm: true
cycle_time: 0.00004
kick_start_time: 0.3
#max_power: 1
#fan_speed: 1
#idle_timeout: 60
#idle_speed: 0.5
#heater: heater_bed, extruder
#stepper: stepper_x, stepper_y, stepper_z

## Fan6
[fan_generic Stepper]
pin: PA2
tachometer_pin: PC1
hardware_pwm: true
cycle_time: 0.00004
kick_start_time: 0.3
#max_power: 1
#fan_speed: 0.8
#idle_timeout: 60
#idle_speed: 0.5
#stepper: stepper_x, stepper_y, stepper_z

### BEEPER ON FAN 3 PIN ###
#[output_pin _beeper]
#pin: PF8
#pwm: true
#value: 0
#shutdown_value: 0
#cycle_time: 0.001

##LED configuration
[led Chamber]
white_pin: PA1
cycle_time: 0.0001
initial_WHITE: 1.0

[mcu]
canbus_uuid: 8e5678e50b21

[printer]
kinematics: corexy
max_velocity: 600
max_accel: 20000
max_z_velocity: 25
max_z_accel: 500
square_corner_velocity: 10

########################################
# TMC2209 configuration
########################################

## Motor1
#[tmc2209 stepper_x]
#uart_pin: PC13
#diag_pin: PF4 
#run_current: 1.2
#hold_current: 1.1
#stealthchop_threshold: 0
#interpolate: true
#sense_resistor: 0.11

## Motor2
#[tmc2209 stepper_y]
#uart_pin: PE3
#diag_pin: PF3
#run_current: 1.2
#hold_current: 1.1
#stealthchop_threshold: 0
#interpolate: true
#sense_resistor: 0.11

## Motor3
#[tmc2209 stepper_z]
#uart_pin: PB9
#diag_pin: PF2
#run_current: 1.0
#hold_current: 0.8
#stealthchop_threshold: 0
#interpolate: true
#sense_resistor: 0.11

## Motor4
#[tmc2209 stepper_]
#uart_pin: PB5
##diag_pin: PF1
#run_current: 0.650
#stealthchop_threshold: 999999

## Motor5
#[tmc2209 extruder]
#uart_pin: PG14
#run_current: 0.800
#stealthchop_threshold: 999999

## Motor6
#[tmc2209 extruder1]
#uart_pin: PG10
#run_current: 0.800
#stealthchop_threshold: 999999

## Motor7
#[tmc2209 extruder2]
#uart_pin: PD5
#run_current: 0.800
#stealthchop_threshold: 999999

## Motor8
#[tmc2209 extruder3]
#uart_pin: PC6
#run_current: 0.800
#stealthchop_threshold: 999999

########################################
# TMC2130 configuration
########################################

## Motor1
[tmc2240 stepper_x]
cs_pin: PC13
spi_software_mosi_pin: PG6
spi_software_miso_pin: PG7
spi_software_sclk_pin: PG8
#diag1_pin: PF4
run_current: 1.2
hold_current: 1.1
stealthchop_threshold: 0
interpolate: True
driver_TOFF: 4
driver_HSTRT: 5
driver_HEND: 2
driver_PWM_FREQ: 1
driver_multistep_filt: True
driver_slope_control: 3

## Motor2
[tmc2240 stepper_y]
cs_pin: PE3
spi_software_mosi_pin: PG6
spi_software_miso_pin: PG7
spi_software_sclk_pin: PG8
#diag1_pin: PF3
run_current: 1.2
hold_current: 1.1
stealthchop_threshold: 0
interpolate: True
driver_TOFF: 4
driver_HSTRT: 5
driver_HEND: 2
driver_PWM_FREQ: 1
driver_multistep_filt: True
driver_slope_control: 3

## Motor3
[tmc2240 stepper_z]
cs_pin: PB9
spi_software_mosi_pin: PG6
spi_software_miso_pin: PG7
spi_software_sclk_pin: PG8
#diag1_pin: PF2
run_current: 1.1
hold_current: 0.9
stealthchop_threshold: 0
interpolate: True
driver_TOFF: 4
driver_HSTRT: 5
driver_HEND: 2
driver_PWM_FREQ: 1
driver_multistep_filt: True
driver_slope_control: 3

## Motor4
#[tmc2130 stepper_]
#cs_pin: PB5
#spi_software_mosi_pin: PG6
#spi_software_miso_pin: PG7
#spi_software_sclk_pin: PG8
##diag1_pin: PF1
#run_current: 0.800
#stealthchop_threshold: 999999

## Motor5
#[tmc2130 extruder]
#cs_pin: PG14
#spi_software_mosi_pin: PG6
#spi_software_miso_pin: PG7
#spi_software_sclk_pin: PG8
#run_current: 0.800
#stealthchop_threshold: 999999

## Motor6
#[tmc2130 extruder1]
#cs_pin: PG10
#spi_software_mosi_pin: PG6
#spi_software_miso_pin: PG7
#spi_software_sclk_pin: PG8
#run_current: 0.800
#stealthchop_threshold: 999999

## Motor7
#[tmc2130 extruder2]
#cs_pin: PD5
#spi_software_mosi_pin: PG6
#spi_software_miso_pin: PG7
#spi_software_sclk_pin: PG8
#run_current: 0.800
#stealthchop_threshold: 999999

## Motor8
#[tmc2130 extruder3]
#cs_pin: PC6
#spi_software_mosi_pin: PG6
#spi_software_miso_pin: PG7
#spi_software_sclk_pin: PG8
#run_current: 0.800
#stealthchop_threshold: 999999

[board_pins]
aliases:
    # EXP1 header
    EXP1_1=PE7, EXP1_2=PG1,
    EXP1_3=PG0, EXP1_4=PF15,
    EXP1_5=PF14, EXP1_6=PF13,    # Slot in the socket on this side
    EXP1_7=PF12, EXP1_8=PF11,
    EXP1_9=<GND>, EXP1_10=<5V>,

    # EXP2 header
    EXP2_1=PE13, EXP2_2=PE12,
    EXP2_3=PE15, EXP2_4=PE11,
    EXP2_5=PE10, EXP2_6=PE14,      # Slot in the socket on this side
    EXP2_7=PE8, EXP2_8=<RST>,
    EXP2_9=<GND>, EXP2_10=<NC>

# See the sample-lcd.cfg file for definitions of common LCD displays.

#[adxl345]
#cs_pin: PA15
#spi_bus: spi3a

#[bltouch]
#sensor_pin: PD13
#control_pin: PD12

## Probe Configuration
[probe]
pin: !PD12
#z_offset: -0.25
speed: 1.5
lift_speed: 5
samples: 2
samples_tolerance_retries: 1

# Bed Mesh Calibration                   
[bed_mesh]                         
speed: 200                          
horizontal_move_z:4
move_check_distance: 5
mesh_min: -105, -105            
mesh_max: 105, 105             
probe_count: 10, 10                  
mesh_pps: 3, 3                     
algorithm: bicubic                 
bicubic_tension: 0.2
fade_start: 0.3
fade_end: 2.4
fade_target: 0

#[output_pin ps_on_pin]
#pin: PD14

#[neopixel my_neopixel_1]
#pin: PD15

#[hall_filament_width_sensor]
#adc1: PC0
#adc2: PF10

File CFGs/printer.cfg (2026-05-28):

[include mainsail.cfg]
[include manta-m8p.cfg]
[include sb2040.cfg]
[include macro.cfg]
[include ad5m-macro.cfg]

[temperature_sensor CM4]
sensor_type: temperature_host

[virtual_sdcard]
path: /home/pi/printer_data/gcodes
on_error_gcode: CANCEL_PRINT

[skew_correction]

[skew_correction skew_profile]
xy_skew = 0.0
xz_skew = 0.0
yz_skew = 0.0

### CONFIG TO BYPASS MOTOR SAFETY ###
#[force_move]
#enable_force_move: true

[homing_override]
gcode:
    # Limit acceleration for homing and moves on print start
    M204 S5000
    G28 Z0
    G28 X0
    G1 X108
    G28 Y0
    G90
    G1 X95 Y95 Z200 F1800

[heater_bed]
#control: pid
#pid_Kp: 74.730
#pid_Ki: 1.724
#pid_Kd: 809.891

[extruder]
#control: pid
#pid_kp: 39.873
#pid_ki: 8.055
#pid_kd: 49.344

# TMC AUTOTUNE SECTION #
#[autotune_tmc stepper_x]
#motor: moons2a
#tuning_goal: performance
#extra_hysteresis: 2

#[autotune_tmc stepper_y]
#motor: moons2a
#tuning_goal: performance
#extra_hysteresis: 2

#[autotune_tmc stepper_z]
#motor: moons2a
#tuning_goal: performance
#extra_hysteresis: 2

#[autotune_tmc extruder]
#motor: extruder
#tuning_goal: performance

#[motor_constants moons2a]
#resistance: 1.05
#inductance: 0.0028
#holding_torque: 0.39
#max_current: 2.0
#steps_per_revolution: 400

#[motor_constants extruder]
#resistance: 2.0
#inductance: 0.0012
#holding_torque: 0.09
#max_current: 1.0
#steps_per_revolution: 200

#*# <---------------------- SAVE_CONFIG ---------------------->
#*# DO NOT EDIT THIS BLOCK OR BELOW. The contents are auto-generated.
#*#
#*# [extruder]
#*# control = pid
#*# pid_kp = 36.941
#*# pid_ki = 7.244
#*# pid_kd = 47.099
#*#
#*# [heater_bed]
#*# control = pid
#*# pid_kp = 75.199
#*# pid_ki = 1.666
#*# pid_kd = 848.804
#*#
#*# [probe]
#*# z_offset = -0.253
#*#
#*# [bed_mesh default]
#*# version = 1
#*# points =
#*# 	0.058625, 0.078937, 0.064250, 0.101437, 0.105812, 0.104250, 0.128937, 0.107062, 0.136125, 0.112375
#*# 	0.111750, 0.122687, 0.106125, 0.099875, 0.111437, 0.116125, 0.130187, 0.134562, 0.148000, 0.115187
#*# 	0.100500, 0.118312, 0.127375, 0.124875, 0.124562, 0.125812, 0.125187, 0.125187, 0.125500, 0.107375
#*# 	0.077687, 0.097687, 0.108625, 0.115500, 0.102375, 0.110500, 0.113000, 0.100500, 0.099250, 0.127375
#*# 	0.050812, 0.079250, 0.085500, 0.107375, 0.102062, 0.115812, 0.125500, 0.104875, 0.089875, 0.117062
#*# 	0.060187, 0.083312, 0.093625, 0.119562, 0.105187, 0.122687, 0.135812, 0.119875, 0.106125, 0.083312
#*# 	0.079562, 0.113625, 0.122687, 0.110812, 0.093312, 0.096750, 0.106750, 0.124562, 0.140812, 0.123000
#*# 	0.087687, 0.105812, 0.122062, 0.123000, 0.081437, 0.075187, 0.110500, 0.124875, 0.136750, 0.117375
#*# 	0.121125, 0.063000, 0.088625, 0.107687, 0.109562, 0.118312, 0.127375, 0.104562, 0.098937, 0.121750
#*# 	0.140500, 0.142062, 0.177687, 0.179875, 0.203937, 0.190500, 0.194250, 0.189875, 0.163000, 0.191125
#*# x_count = 10
#*# y_count = 10
#*# mesh_x_pps = 3
#*# mesh_y_pps = 3
#*# algo = bicubic
#*# tension = 0.2
#*# min_x = -105.0
#*# max_x = 104.96999999999997
#*# min_y = -105.0
#*# max_y = 101.46
#*#
#*# [input_shaper]
#*# shaper_type_x = mzv
#*# shaper_freq_x = 60.6
#*# shaper_type_y = mzv
#*# shaper_freq_y = 51.4

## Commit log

2026-05-28 Changed file directories
    [extruder-x1-sb2040-mk5-body-lightweight.stl, extruder-x1-sb2040-mk5-body-nozzlecover.stl, extruder-x1-sb2040-mk5-cap-frontconnectorcover.stl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]
2026-05-28 renamed folder
    [5in-screen-frontbezel.stl, 5in-screen-rearbezel.stl, ad5m-backpanel-spacer-bottom-left.stl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]
